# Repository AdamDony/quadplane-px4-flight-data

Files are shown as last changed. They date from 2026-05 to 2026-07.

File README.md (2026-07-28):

# Quadplane VTOL — Flight-Test Telemetry, CFD & Structural Data






Complete engineering dataset for a small **quadplane VTOL** (fixed wing + quad
lift motors): real flight-test telemetry through both hover ⇄ forward-flight
transitions, Ansys Fluent CFD of the S1223 wing, gust-response cases,
structural FEA, and the CAD geometry — with a Python toolkit that regenerates
every figure below straight from the raw logs.

> **Flight-Test Characterization and Design Implications of
> Hover-to-Forward-Flight Transition for a Small Quadplane VTOL Aircraft**
> Md Azizul Islam, Md Nur-A-Adam Dony\*, Mehedi Hasan, S. G. M. Hossain
> \* Corresponding author — `mdony42@tntech.edu`
> 📄 **[Read the paper (preprint PDF)](docs/preprint.pdf)**
> Journal manuscript, 2026 (under review)

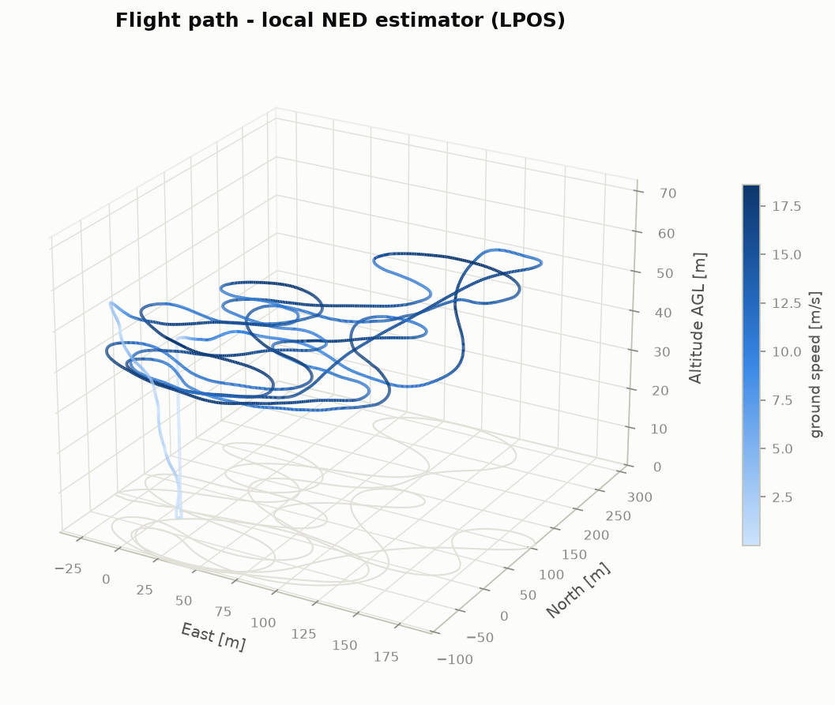
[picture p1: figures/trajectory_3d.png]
3-D flight path reconstructed from the PX4 local-position estimator


## The flight at a glance

Recorded **4 September 2022** over an open agricultural field near Dhaka,
Bangladesh (23.85° N, 90.51° E). One battery, one continuous log: vertical
take-off on four lift rotors, transition to wing-borne cruise, ~4 min of
pattern flying, back-transition, and vertical landing.

| | |
|---|---|
| Log session / flight time | 24.0 min / ~6 min |
| Distance flown | **3.6 km** |
| Max altitude (AGL) | **69 m** |
| Cruise indicated airspeed | **≈ 15 m/s** (18.6 m/s peak ground speed) |
| Power in stable hover | **≈ 1 270 W** |
| Power in wing-borne cruise | **≈ 380 W — 3.4× less than hover** |
| Energy used | 2 695 mAh (6S Li-Po) |

That 3.4× hover-to-cruise power ratio *is* the quadplane argument, and you can
see it in the data:

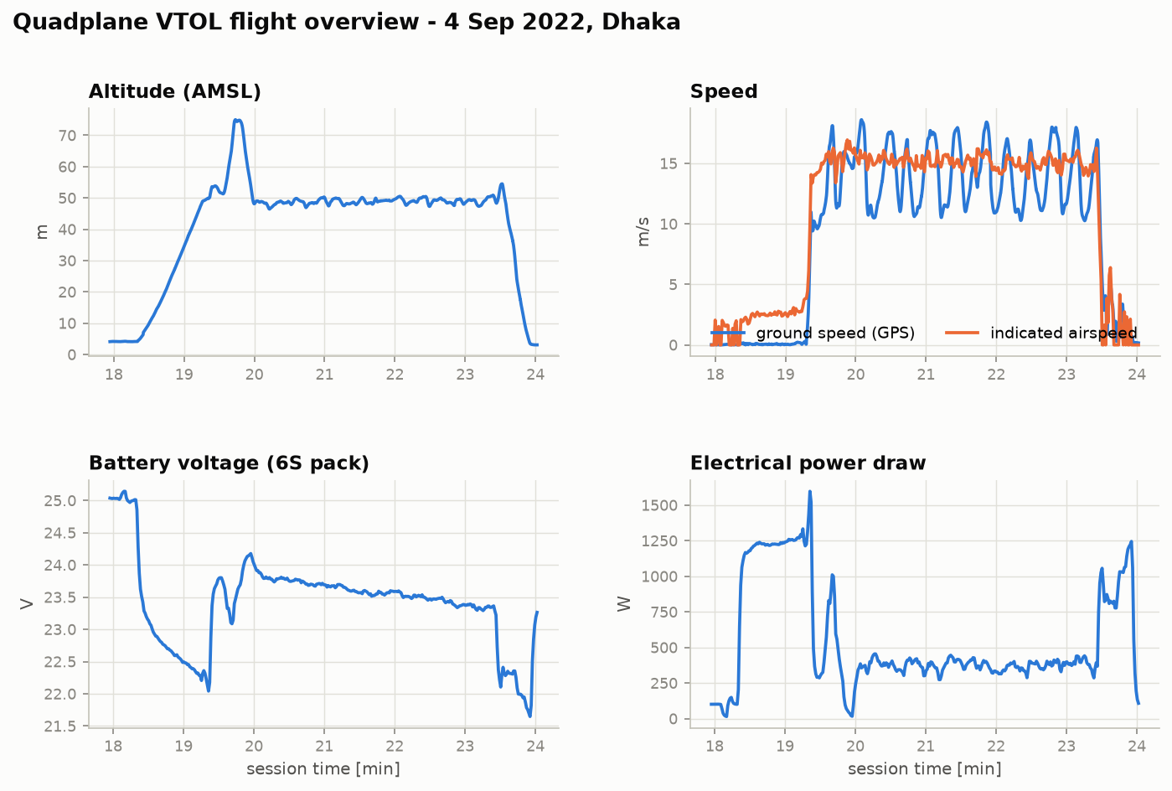
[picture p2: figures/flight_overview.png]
Altitude, speed, battery voltage and power over the flight


The transition itself — quad lift motors throttle up for the vertical climb,
shut off completely at 19.4 min as the wing takes the load, then re-engage at
23.4 min for the back-transition and landing:

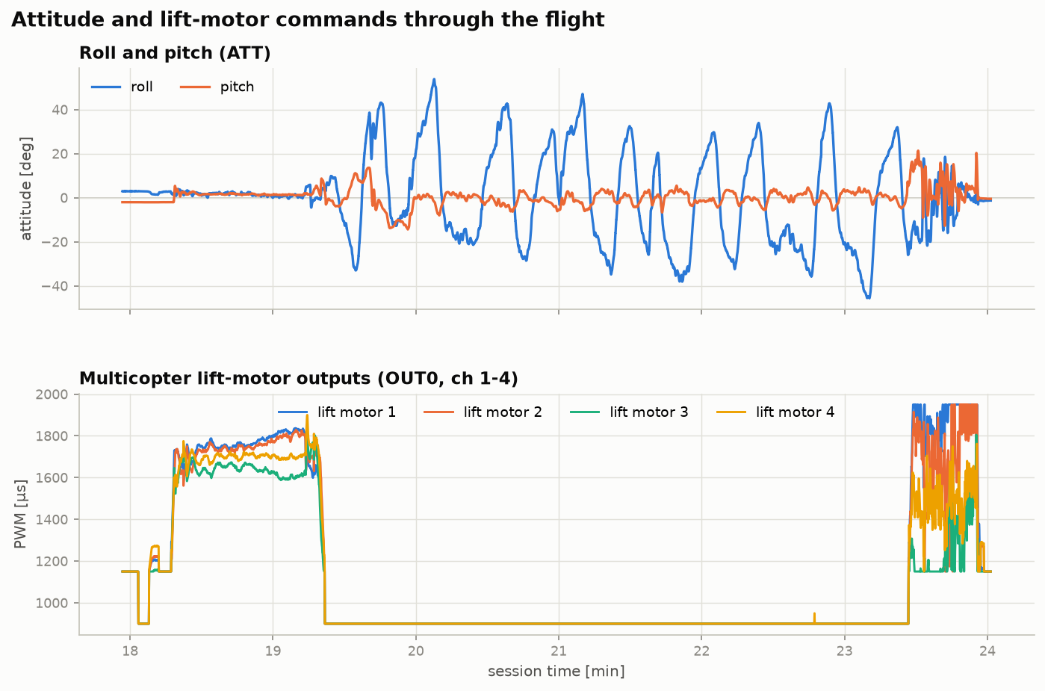
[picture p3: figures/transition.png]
Attitude and lift-motor PWM through both transitions


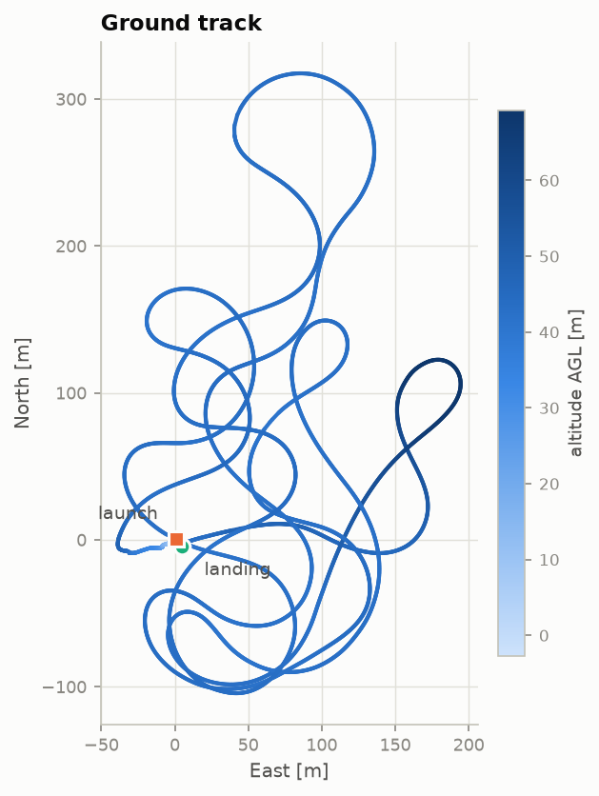
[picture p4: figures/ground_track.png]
Top-down ground track coloured by altitude


**Reproduce all figures** (≈10 s, no autopilot tooling required):

```bash
pip install -r analysis/requirements.txt
python analysis/plot_flight.py
```

---

## Repository map

```
├── data/telemetry/     13 PX4 topic CSVs from the flight log  → docs/DATA_DICTIONARY.md
├── analysis/           Python toolkit that generates figures/ from the CSVs
├── figures/            Flight-report figures (regenerable)
├── cfd/
│   ├── aoa-sweep/      Fluent pressure/lift/drag fields, α = −5° … +20°
│   ├── gust-cases/     Gust-perturbation lift & drag time-histories
│   ├── polars/         Aggregated Cl/Cd data (LiftDrag.xlsx) and plots
│   ├── flow-viz/       Streamlines, vectors, contours, residuals, case setup
│   └── projects/       Ansys Workbench projects (.wbpj + archives)
├── fea/                Wing structural FEA (deformation, stress, strain)
├── airfoil/            S1223 coordinates & meshing scripts (10″, 11.5″ chord, winglet)
├── cad/                SolidWorks parts, STEP export, AutoCAD drawing, renders
├── media/              Flight-test video
└── docs/               Data dictionary, paper source bundle (AIAA.zip)
```

---

## 1. Flight telemetry — `data/telemetry/`

Source binary log: `log_5_2022-9-4-18-02-56.px4log` (PX4 **v1.7.0**, legacy
`sdlog2` format), split into per-topic CSVs with `sdlog2_dump.py` from the
[PX4 v1.7.0 release tag](https://github.com/PX4/PX4-Autopilot/tree/v1.7.0).
Full column-level semantics: **[docs/DATA_DICTIONARY.md](docs/DATA_DICTIONARY.md)**.

| CSV | Topic | ~Rate | Highlights |
|---|---|---|---|
| `ATT.csv` | Attitude (quaternion, Euler, body rates) | 22 Hz | Transition body-rate peaks |
| `ATSP.csv` | Attitude setpoint | 22 Hz | Commanded pitch through transition |
| `ARSP.csv` | Attitude-**rate** setpoint (inner loop) | 86 Hz | Rate-controller commands |
| `AIRS.csv` | Airspeed (indicated / true) | 1 Hz | Transition speed, cruise IAS |
| `LPOS.csv` | Local NED position estimate | 22 Hz | 3-D trajectory, climb rates |
| `LPSP.csv` | Local position setpoint | event | Tracking error |
| `GPOS.csv` | Global position estimate | 22 Hz | Ground track, altitude |
| `GPS.csv` | Raw GNSS (+ the only absolute clock) | 1 Hz | Fix quality, 32 satellites |
| `OUT0.csv` | Actuator PWM, main bank | 10 Hz | Lift-motor shutoff / re-engagement |
| `RC.csv` | Pilot radio input | 9 Hz | Stick inputs |
| `BATT.csv` | Battery V / I / consumed mAh | 1 Hz | Per-phase power & energy |
| `PWR.csv` | 5 V rail health | 1 Hz | Power-system diagnostics |
| `STAT.csv` | System state (mode, arming, land detector) | event | Flight-phase segmentation |

> **Note.** `ARSP` in `sdlog2` is the attitude-*rate* setpoint topic, not
> airspeed — airspeed lives in `AIRS`. Newer PX4 releases use ULog (`.ulg`);
> the pipeline here is specific to the legacy `sdlog2` format.

## 2. CFD — Ansys Fluent, S1223 wing section

2-D angle-of-attack sweep with the SST k–ω turbulence model
(y⁺ ≲ 1 C-grid, V∞ = 15 m/s, ρ = 1.225 kg/m³, turbulence intensity 1 %).

- **`cfd/aoa-sweep/`** — pressure-field + integrated lift/drag exports at
  α = −5°, 0°, +5°, +10°, +15°, +20° (`AnsysSimu{α}AOA{Lift|Drag}.JPG`).
- **`cfd/gust-cases/`** — `15AoA{45|60}Gusted{2|4|6|8}MS{Lift|Drag}.jpg`:
  lift/drag time-histories at base α = +15° under 2–8 m/s gusts at 45°/60°
  orientation, plus static cases `{Lift|Drag}0AoA{30…135}Degree8ms.JPG`.
  The ~33 % gust lift-drop result in the paper comes from the 2 m/s case.
- **`cfd/polars/`** — [`LiftDrag.xlsx`](cfd/polars/LiftDrag.xlsx): the raw
  integrated Fluent forces behind the paper's polar figure, with plot exports.
  Run `python analysis/cfd_polars.py` to reduce them to finite-wing
  coefficients for the simulated panel geometry (`cad/WingForSimu.STEP`,
  0.292 m chord × 1.016 m span, AR 3.48): C_Lα ≈ 2.64/rad, C_D0 ≈ 0.018,
  Oswald e ≈ 0.77, max L/D ≈ 10.
- **`cfd/flow-viz/`** — streamlines, velocity vectors, pressure contours,
  particle traces, residual/convergence history, and solver-setup screenshots.
- **`cfd/projects/`** — Ansys Workbench projects: `GustedWingProjectANSYS.wbpj`
  (AoA sweep) and `GustedWind.wbpj` (gust cases) + supporting archive.
  Requires Workbench 2022 R2 / 2023 R1 with a Fluent licence.

## 3. Structural FEA — `fea/`

Static pressure loading of the wing at 100 / 200 / 300 Pa equivalent inflow
pressure: total deformation (`Deform*Pa.JPG`), von-Mises and normal
stress/strain at 200 Pa, and the full Workbench Mechanical project
(`FEAWing_files.zip`).

## 4. Airfoil — `airfoil/`

The wing uses the low-Reynolds, high-lift **Selig S1223** section:
baseline coordinates (`S1223.xlsx`), chord scalings to 10″ and 11.5″,
winglet planform points, and the XFOIL/Fluent meshing scripts (`*.docx`).

## 5. CAD — `cad/`

SolidWorks wing and arm solids (`*.SLDPRT`), neutral `WingForSimu.STEP`
export for re-meshing in any tool, AutoCAD assembly drawing
(`Drawing1.dwg` / `Drawing1-Model.pdf`), and renders in `cad/renders/`.

## 6. Media — `media/`

Flight-test video from the 5 September 2022 session
([`VID-20220905-WA0012.mp4`](media/VID-20220905-WA0012.mp4)).

---

## Citing this work

If you use any data, figures, or analysis from this repository, please cite
the paper (machine-readable metadata in [`CITATION.cff`](CITATION.cff)):

```bibtex
@article{IslamDonyHossain2026Quadplane,
  author  = {Islam, Md Azizul and Dony, Md Nur-A-Adam and Hasan, Mehedi and Hossain, S. G. M.},
  title   = {{Flight-Test Characterization and Design Implications of
             Hover-to-Forward-Flight Transition for a Small Quadplane VTOL Aircraft}},
  year    = {2026},
  note    = {Journal manuscript under review}
}
```

Volume, pages, and DOI will be added on acceptance.

## License

Data, figures, and analysis code are released under
**[CC BY 4.0](LICENSE)**. Ansys project files are © the authors (CC-BY-4.0;
opening them requires your own Ansys licence — no Ansys software is
redistributed). The paper source bundle (`docs/AIAA.zip`) follows the
journal's author-rights policy.

## Contact

**Md Nur-A-Adam Dony** — `mdony42@tntech.edu`
Department of Electrical and Computer Engineering,
Tennessee Technological University, Cookeville, TN, USA

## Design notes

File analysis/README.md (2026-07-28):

# Analysis toolkit

Reproduces every figure in [`figures/`](../figures/) directly from the raw
telemetry CSVs in [`data/telemetry/`](../data/telemetry/).

```bash
pip install -r analysis/requirements.txt
python analysis/plot_flight.py            # flight figures (run from the repo root)
python analysis/cfd_polars.py             # CFD polar reduction -> figures/cfd_polars.png
```

Output (≈10 s):

| Figure | Contents |
|---|---|
| `figures/flight_overview.png` | Altitude, ground speed + indicated airspeed, battery voltage, electrical power |
| `figures/trajectory_3d.png` | 3-D flight path (local NED), coloured by ground speed |
| `figures/ground_track.png` | Top-down ground track, coloured by altitude AGL |
| `figures/transition.png` | Roll/pitch and quad lift-motor PWM through both VTOL transitions |
| `figures/cfd_polars.png` | Finite-wing C_L/C_D polars and induced-drag fit reduced from `cfd/polars/LiftDrag.xlsx` |

## Time-base caveat

The `sdlog2` CSV exports carry no per-row timestamp; only `GPS.csv` has an
absolute clock (`GPS_GPSTime`, µs). The script assigns each topic a uniform
time axis spanning the GPS-derived 24.02-min session. This is good to within
logger scheduling jitter and is intended for visualisation and phase-level
interpretation — not for spectral analysis. See
[`docs/DATA_DICTIONARY.md`](../docs/DATA_DICTIONARY.md) for column semantics.

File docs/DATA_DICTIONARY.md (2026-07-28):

# Telemetry data dictionary

Column-level reference for the 13 PX4 topic exports in [`data/telemetry/`](../data/telemetry/).

**Source log:** `log_5_2022-9-4-18-02-56.px4log` — PX4 v1.7.0, legacy `sdlog2`
binary format, extracted per-topic with `sdlog2_dump.py` from the
[PX4-Autopilot v1.7.0](https://github.com/PX4/PX4-Autopilot/tree/v1.7.0) release tag.

**Session:** 24.02 min total (bounded by the `GPS_GPSTime` microsecond clock),
of which the final ~6 min is the actual flight (arm → VTOL take-off →
transition → fixed-wing cruise → back-transition → landing).

**Time base:** the CSV rows do not carry a per-row timestamp column. Each topic
is logged at an approximately fixed rate while the logger runs, so a uniform
time axis over the 24.02-min session (as done in
[`analysis/plot_flight.py`](../analysis/plot_flight.py)) is accurate to within
scheduler jitter — sufficient for visualisation and phase-level analysis, not
for spectral/rate-sensitive work. The "rate" column below is simply
`rows / session length`.

Angles are radians, positions metres, velocities m/s, following PX4 `sdlog2`
conventions (NED frame: X north, Y east, Z **down**).

---

## ATT — vehicle attitude (~22 Hz, 31 885 rows)

| Column | Meaning |
|---|---|
| `ATT_qw, ATT_qx, ATT_qy, ATT_qz` | Attitude quaternion (body → NED) |
| `ATT_Roll, ATT_Pitch, ATT_Yaw` | Euler angles [rad] |
| `ATT_RollRate, ATT_PitchRate, ATT_YawRate` | Body angular rates [rad/s] |
| `ATT_GX, ATT_GY, ATT_GZ` | Estimated ground-relative velocity components (unused in this log) |

## ATSP — attitude setpoint (~22 Hz, 31 746 rows)

| Column | Meaning |
|---|---|
| `ATSP_RollSP, ATSP_PitchSP, ATSP_YawSP` | Commanded Euler angles [rad] |
| `ATSP_ThrustSP` | Normalised thrust setpoint [0–1] |
| `ATSP_qw…ATSP_qz` | Setpoint quaternion |
| `ATSP_fwy, ATSP_dmcy, ATSP_af, ATSP_tm, ATSP_eon, ATSP_di` | Controller flags (fw yaw-wheel, disable mc yaw, apply flaps, thrust-major, enabled, direct-input) |

## ARSP — attitude *rate* setpoint (~86 Hz, 123 738 rows)

| Column | Meaning |
|---|---|
| `ARSP_RollRateSP, ARSP_PitchRateSP, ARSP_YawRateSP` | Commanded body rates [rad/s] — inner-loop setpoints |

> Note: despite the name, `ARSP` in `sdlog2` is the attitude-**rate** setpoint
> topic, not airspeed. Airspeed is in `AIRS`.

## AIRS — airspeed (~1 Hz, 1 445 rows)

| Column | Meaning |
|---|---|
| `AIRS_IndSpeed` | Indicated airspeed [m/s] |
| `AIRS_TrueSpeed` | True airspeed [m/s] |
| `AIRS_AirTemp` | Air temperature [°C] |
| `AIRS_Conf` | Sensor confidence [0–1] |

## LPOS — local position estimate (~22 Hz, 31 157 rows)

| Column | Meaning |
|---|---|
| `LPOS_X, LPOS_Y, LPOS_Z` | Local NED position [m] (Z positive **down**) |
| `LPOS_Dist, LPOS_DistR` | Distance-sensor reading and rate |
| `LPOS_VX, LPOS_VY, LPOS_VZ` | NED velocity [m/s] |
| `LPOS_RLat, LPOS_RLon, LPOS_RAlt` | Local-frame reference origin (lat/lon/alt) |
| `LPOS_PFlg, LPOS_GFlg` | Position / ground-distance validity flags |
| `LPOS_EPH, LPOS_EPV` | Horizontal / vertical position std-dev [m] |

## LPSP — local position setpoint (event, 6 599 rows)

| Column | Meaning |
|---|---|
| `LPSP_X, LPSP_Y, LPSP_Z, LPSP_Yaw` | Position + yaw setpoint |
| `LPSP_VX, LPSP_VY, LPSP_VZ` | Velocity setpoint [m/s] |
| `LPSP_AX, LPSP_AY, LPSP_AZ` | Acceleration setpoint [m/s²] |

## GPOS — global position estimate (~22 Hz, 31 010 rows)

| Column | Meaning |
|---|---|
| `GPOS_Lat, GPOS_Lon` | WGS-84 latitude / longitude [deg] |
| `GPOS_Alt` | Altitude AMSL [m] |
| `GPOS_VelN, GPOS_VelE, GPOS_VelD` | NED velocity [m/s] |
| `GPOS_EPH, GPOS_EPV` | Position accuracy estimates [m] |
| `GPOS_TALT` | Terrain altitude [m] (−1 = invalid) |

## GPS — raw GNSS (~1 Hz, 1 484 rows)

| Column | Meaning |
|---|---|
| `GPS_GPSTime` | GPS epoch time [µs] — **the only absolute clock in the dataset** |
| `GPS_Fix` | Fix type (4 = 3D-RTK class fix in this log) |
| `GPS_EPH, GPS_EPV` | Horizontal / vertical accuracy [m] |
| `GPS_Lat, GPS_Lon, GPS_Alt` | Raw receiver position |
| `GPS_VN, GPS_VE, GPS_VD` | Receiver NED velocity [m/s] |
| `GPS_Cog` | Course over ground [rad] |
| `GPS_nSat` | Satellites used |
| `GPS_SNR, GPS_N, GPS_J, GPS_H` | Signal metrics (noise, jamming indicator/level) |

## OUT0 — actuator outputs, main bank (~10 Hz, 13 792 rows)

| Column | Meaning |
|---|---|
| `OUT0_Out0 … OUT0_Out3` | Quad lift-motor PWM [µs] (900 = off, ≈1150 = armed idle) |
| `OUT0_Out4 … OUT0_Out7` | Remaining main-bank channels (fixed-wing surfaces / pusher) |

## RC — pilot radio input (~9 Hz, 13 534 rows)

| Column | Meaning |
|---|---|
| `RC_C0 … RC_C11` | Normalised channel values [−1 … 1] |
| `RC_RSSI` | Link signal strength |
| `RC_CNT, RC_Lost, RC_Drop` | Frame counter, link-lost flag, drop count |

## BATT — battery status (~1 Hz, 1 442 rows)

| Column | Meaning |
|---|---|
| `BATT_VFilt` | Filtered pack voltage [V] (6S Li-Po) |
| `BATT_CFilt` | Filtered current [A] |
| `BATT_Discharged` | Consumed charge [mAh] |
| `BATT_Remaining, BATT_RemainingV` | Remaining-capacity estimates [0–1] |
| `BATT_Warning` | Low-battery warning level |

## PWR — power-rail status (~1 Hz, 1 439 rows)

| Column | Meaning |
|---|---|
| `PWR_Periph5V, PWR_Servo5V` | 5 V peripheral / servo rail voltages [V] |
| `PWR_RSSI` | RSSI analog input |
| `PWR_UsbOk, PWR_BrickOk, PWR_ServoOk` | Power-source validity flags |
| `PWR_PeriphOC, PWR_HipwrOC` | Over-current flags |

## STAT — system status (event, 7 237 rows)

| Column | Meaning |
|---|---|
| `STAT_NavState` | Navigation/flight-mode state (0 = manual, 3 = mission/auto in this log) |
| `STAT_ArmS` | Arming state |
| `STAT_Failsafe` | Failsafe active flag |
| `STAT_Landed` | Land-detector output |
| `STAT_Load` | CPU load [0–1] |

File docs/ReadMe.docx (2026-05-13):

- WingForSimu.SLDPRT is the SolidWorks part file used for doing CFD ANSYS Fluent Analysis
- Drawing1.dwg is the AutoCAD file for 2D wing drawing
- WingDraft2.SLDPRT is the SolidWorks part file for wing 3D Modeling
- Any files that start with S1223 is the files contain the xy coordinates of S1223 airfoil that is used in SolidWorks 3D modeling
- The rest of the files are screenshots of various things

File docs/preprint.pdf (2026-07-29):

# Flight-Test Characterization and Design Implications of Quadplane Hover-to-Forward-Flight Transition

Md Azizul Islam∗

# KaiLab LLC, Sugar Land, TX 77479, United States

Md Nur-A-Adam Dony†

# Tennessee Technological University, Cookeville, TN 38505, United States

Mehedi Hasan‡

# University of Arkansas, Fayetteville, AR 72701, United States

S. G. M. Hossain§

# Blue Origin, Kent, WA 98032, United States

Hybrid vertical take-off and landing aircraft that combine multirotor lift with a fixed wing

pair the operational flexibility of a multicopter with the cruise efficiency of an airplane, at the

cost of a mode-switching transition that must remain reliably stable. This paper reports a

flight-test characterization of the hover phase, the hover-to-forward-flight transition, and the

fixed-wing cruise of a small quadplane, using telemetry recorded by an open-source autopilot,

complemented by a computational aerodynamic study of the wing. Body angular rates, attitude

excursions, ground speed, electrical power, bank-angle distributions, and elevator trim are

extracted from the on-board estimator and cross-validated against numerical derivatives of

the recorded attitude quaternion. The aircraft exhibits a stationary hover, a smooth front

transition completing at an airspeed of 11.9 meters per second, and a back transition completing

in 1.86 seconds, with peak body-axis rates well within control authority. The hover-to-cruise

electrical-power ratio is 3.36. An angle-of-attack sweep of a finite wing panel resolves the lift

and drag polars, identifies the onset of stall, and quantifies an approximately 33 percent lift

loss under a quasi-steady airspeed deficit, anchoring an operational wind ceiling. Design rules

for airspeed margin, control authority, power sizing, energy budget, and wind tolerance are

derived.

# Nomenclature

∗Research and Development Specialist, UAV Design and Manufacture; azizul@kailab.com.

†Ph.D. Candidate, Department of Electrical and Computer Engineering; mdony42@tntech.edu (Corresponding Author).

‡Graduate Research Assistant, Department of Mechanical Engineering; mehedih@uark.edu.

§Senior Manufacturing Engineer, Lunar Permanence Program; smgmamur@yahoo.com.

φ, θ, ψ | = | roll, pitch, yaw angles, rad (deg where stated)
p, q, r | = | body-axis angular rates, rad/s (deg/s where stated)
qw, qx, qy, qz | = | unit attitude quaternion components
VN , VE, VD | = | north–east–down (NED) frame ground velocity, m/s
Vℎ | = | horizontal ground speed, m/s
Vair | = | indicated airspeed (IAS) from pitot, m/s
VT, VT,back | = | front and back transition airspeeds, m/s
Vc | = | cruise airspeed, m/s
ℎ, ℎ¤ | = | altitude above ground level and climb rate, m, m/s
δe, δa, δr | = | elevator, aileron, rudder deflection, deg
R | = | turn radius, m
P, E | = | electrical power and energy, W, W·h
Vbat, I | = | battery pack voltage and current, V, A
L, D, T | = | aerodynamic lift, drag, and thrust, N
CL, CD, CM | = | lift, drag, and pitching-moment coefficients
CLα | = | lift-curve slope, rad−1
α | = | angle of attack, rad (deg where stated)
n | = | load factor
W | = | aircraft weight, N
g | = | gravitational acceleration, m/s2
ρ, μ | = | air density and dynamic viscosity, kg/m3
, Pa·s
S, c, b | = | wing reference area, chord, and span, m2
, m, m
Re | = | chord Reynolds number
ηprop, ηESC | = | propeller and electronic-speed-controller efficiency
Nr | = | number of lift rotors
Ad | = | single-rotor disc area, m2
σ | = | sample standard deviation

# I. Introduction

# A. Background and Motivation

H

ybrid VTOL UAVs combine the runway-independent operation of a multicopter with the cruise efficiency of a

fixed-wing aircraft, and have become a preferred platform for medium-range surveillance, mapping, and logistics missions [1, 2]. The development of small UAV airframes has progressed from early FPGA-based remote-piloted

platforms [3] and digital multi-rotor control systems [4] toward autonomous open-source autopilot ecosystems, and

wing design choices for small UAVs now span fixed cambered low-Reynolds-number sections to more sophisticated

morphing-airfoil concepts [5–7]. Among hybrid configurations, the quadplane—a conventional airplane retrofitted with

four dedicated lift rotors—offers the simplest control architecture: the multicopter (MC) and fixed-wing (FW) flight

modes are mechanically decoupled, and the autopilot manages a single coordinated handover during transition. The

trade-off is that the lift rotors carry parasitic mass and drag in cruise, while the wing and pusher are unused in hover, so

the platform must be efficient enough in cruise to amortize the parasitic systems [8]. The test vehicle used in this study

is shown at rest in Fig. 1, with the composite-skinned airframe, twin lift booms, and rear pusher motor visible.

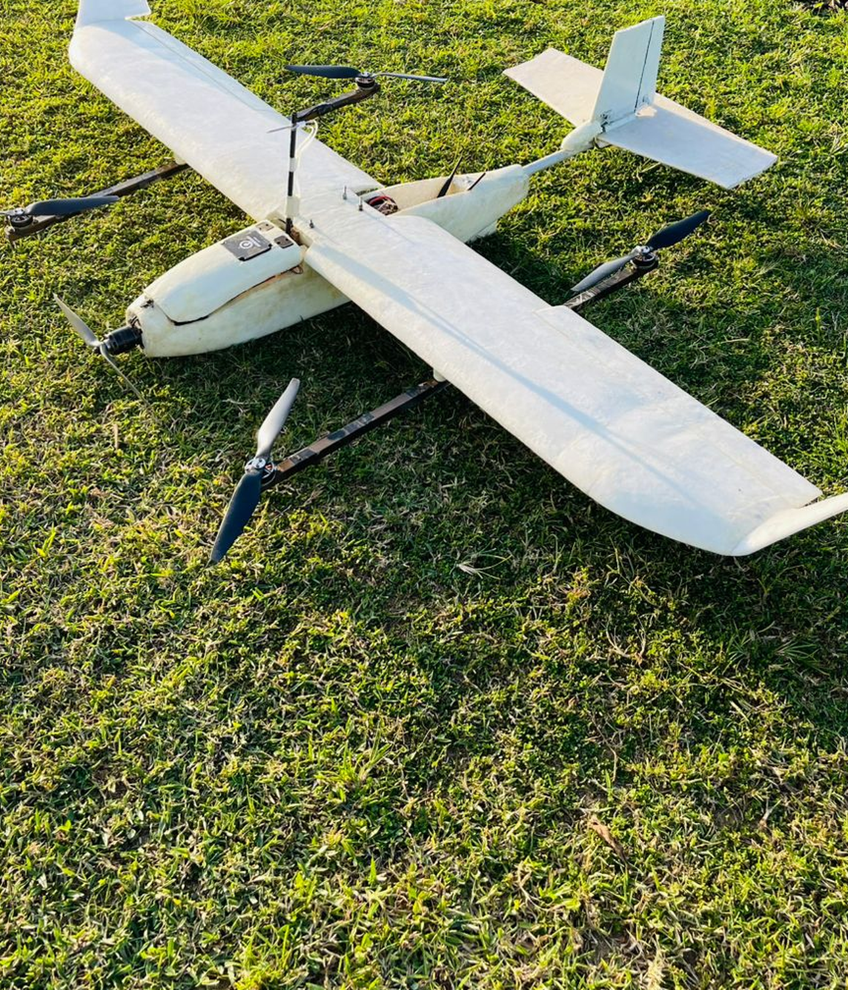
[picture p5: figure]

Fig. 1 Test vehicle at rest: a small quadplane with four boom-mounted lift rotors and a rear pusher propeller.

The most demanding flight regime is the front transition (MC→FW), during which the wing must develop sufficient

lift to support the aircraft before the lift rotors are commanded off. If transition is initiated too slowly, the wing stalls; if

too quickly, the lift rotors saturate while fighting decelerating wing downwash [9, 10]. Practical PX4-class autopilots

manage this trade through a single threshold airspeed VT at which the controller commits to FW.∗ Robust transition is

therefore a stability problem first—the airframe must remain trim during a regime change in which control authority

transfers from rotors to aerodynamic surfaces—and a design problem second—the airframe must possess sufficient

power, control, and aerodynamic margins to accommodate the worst-case excursion.

∗PX4 User Guide: VTOL Aircraft Configuration, https://docs.px4.io/main/en/frames_vtol/ [retrieved 12 May 2026].

# B. Related Work

The literature on small VTOL UAV transition control spans three configurations. Tail-sitter aircraft have dominated

empirical work: Beach et al. [11] introduced a resolved tilt-twist attitude representation that avoids the Euler-angle

singularities of a 90° pitch swing, Lyu et al. [12] demonstrated hierarchical attitude control on a quadrotor tail-sitter,

Verling et al. [13] reported full-attitude transition on a flying-wing tail-sitter, Kubo and Suzuki [14] characterized

tail-sitter transitional flight, and Ritz and D’Andrea [15] introduced a global flight-envelope controller for flying-wing

tail-sitters. Tilt-rotor and tilt-wing aircraft have been studied by Maqsood and Go [9] on transition optimization,

Geuther et al. [16] on a NASA tandem tilt-wing demonstrator, Yeh et al. [17] on an inverse machine-learning approach

to tilt-wing takeoff, and May et al. [18] on tilt-wing transition strategies. Quadplanes have received comparatively

less empirical attention: Mathur and Atkins [19] reported an experimental aerodynamic analysis of a quadplane UAS

in the wind tunnel, Lee and Kim [20] proposed MPC-based longitudinal control for a fixed-wing VTOL, Liu et al.

[10] demonstrated INDI transition control on a small VTOL, and Chiwande et al. [21] presented adaptive transition

control for quadplane VTOLs in urban gust environments. Survey work [1, 2, 8] consistently identifies the lift+cruise

quadplane as the simplest and most energy-efficient hybrid topology for medium-range missions. The control-theoretic

background for VTOL and related aerospace platforms is a parallel theme: parametric-uncertainty tracking control for

VTOL vehicles has been developed in [22], distributed formation control of spacecraft and higher-order-dynamics UAVs

in [23, 24], command-filtered robust tracking on marine and surface platforms in [25], and safe reinforcement-learning

control with control barrier functions in [26, 27], providing complementary algorithmic context for the experimental

characterization reported here.

# C. Comparison with Existing Methods and Contributions

Three characteristics of prior empirical literature motivate the present work. First, many published flight-test

characterizations rely on proprietary autopilot stacks whose raw telemetry is not openly accessible. Second, the bulk of

VTOL transition work is simulation-led, with flight data appearing as a single validation point rather than the primary

characterization tool. Third, the configuration-specific literature is heavily weighted toward tail-sitter and tilt-rotor

designs, while empirical studies that report stability margins, transition timing, power budgets, and aerodynamic

interpretation jointly on a quadplane platform are sparse.

Table 2 summarizes the scope of representative prior studies and contrasts each with the present work along

eight axes: aircraft configuration, methodology, primary data source, transition-airspeed reporting, transition-duration

reporting, power-budget reporting, lateral-directional characterization, and CFD aerodynamic interpretation. No prior

study in the table simultaneously satisfies the joint empirical+CFD+design-rule scope on a quadplane platform.

This paper contributes the following, none of which is jointly addressed in the prior literature reviewed:

1) Configuration focus on quadplanes. Where prior empirical transition work largely targets tail-sitters [11–15]

Table 2 Comparison of the present work with representative prior literature on small VTOL UAV transition. ✓ = reported in primary text; ✗ = not reported. Configuration codes: TS = tail-sitter; FW = flying-wing; Quad. = quadrotor. Data codes: “Emp.” = empirical (real-flight); “Sim.” = simulation; “WT” = wind tunnel.

Reference | Config. | Methodology | Data | VT | Dur. | Pow. | Lat./dir. | CFD
Beach 2014 [11] | TS | Tilt-twist attitude | Sim.+flight | ✗ | ✗ | ✗ | ✗ | ✗
Lyu 2017 [12] | Quad. TS | Hierarchical attitude | Emp. | ✓ | ✓ | ✗ | partial | ✗
Verling 2016 [13] | FW TS | Full-attitude | Emp. | ✓ | ✓ | ✗ | ✓ | ✗
Kubo 2008 [14] | TS | Transitional flight | Emp.+WT | ✓ | ✓ | ✗ | ✗ | WT
Ritz 2017 [15] | FW TS | Global envelope | Emp. | ✓ | ✓ | ✗ | ✓ | ✗
Maqsood 2012 [9] | Tilt-rotor | Aerodynamic vectoring | Sim. | ✓ | ✓ | ✗ | ✗ | Invisc.
Geuther 2020 [16] | Tilt-wing | Sub-scale free-flight | Emp. | ✓ | partial | ✗ | partial | ✗
Yeh 2023 [17] | Tilt-wing | Inverse-ML takeoff | Sim. | ✓ | ✗ | ✗ | ✗ | ✗
May 2024 [18] | Tilt-wing | Transition strategy | Sim. | ✓ | ✓ | ✗ | partial | ✗
Mathur 2023 [19] | QuadPlane | Wind-tunnel aerodynamics | WT | ✗ | ✗ | ✗ | ✗ | ✓ (WT)
Lee 2024 [20] | FW VTOL | MPC longitudinal | Sim. | ✓ | ✗ | ✗ | ✗ | ✗
Chiwande 2025 [21] | QuadPlane | INAV adaptive gust | Emp. | partial | ✗ | ✗ | partial | ✗
This work | Quadplane | PX4 sdlog2 + Fluent CFD | Emp.+CFD | ✓ | ✓ | ✓ | ✓ | ✓ (CFD)

or tilt-wing and tilt-rotor airframes [9, 16–18], this paper provides a flight-test characterization of a small

quadplane—a configuration that remains under-represented in the empirical literature [1, 19].

2) Open, reproducible methodology. The telemetry pipeline operates exclusively on the open-source PX4 sdlog2

record. Every derived state—quaternion-to-Euler, body rates, ground speed, wind, power, energy, bank, turn

radius, elevator trim—is cross-validated against firmware-stored fields, and per-topic CSV bundles are released

(see Data Availability). The wind-tunnel work of Mathur and Atkins [19] provides aerodynamic data on a

comparable platform; the present approach complements it with real-flight evidence.

3) Joint longitudinal and lateral-directional characterization on a single flight. Body-rate, attitude, transition-

timing, bank-angle distribution, coordinated-turn cross-check, and elevator-trim results are derived from the

same flight log. No reviewed quadplane study reports all six on real flight data.

4) CFD aerodynamic interpretation with gust anchoring. An Ansys Fluent angle-of-attack sweep of a finite-span

S1223 wing panel gives CL (α) and CD (α) polars with a quantitative drag-polar decomposition (zero-lift drag

and Oswald factor), multi-AoA pressure contours, flow visualization, and a quasi-steady airspeed-deficit case

that converts the empirical VT threshold into a physically anchored, gust-margin-quantified design quantity.

5) Inequality-form design rules. Airspeed margin, control authority, power-system sizing, energy budget, and

operational wind ceiling are translated from the combined empirical and CFD evidence into compact design

inequalities (Sec. VIII).

The results derive from a single flight on one airframe and constitute a case study; broader statistical validation

through additional flights and platforms is identified as the central future-work theme (Sec. IX).

The remainder of the paper is organized as follows. Section II presents the mathematical preliminaries. Section III describes the data-extraction and CFD methodologies, together with the aerodynamic and energetic relations specific to

the quadplane configuration. Sections IV and V describe the test vehicle and the experimental setup. Section VI reports

the flight-test results. Section VII presents the computational aerodynamic analysis. Section VIII extracts the design

implications, and Section IX concludes.

# II. Preliminaries

This section establishes the mathematical framework used to derive aircraft states from the recorded PX4 telemetry

and from the complementary CFD sweep. All symbols are defined in the Nomenclature.

# A. Attitude Representation

The aircraft attitude is stored on board as a unit quaternion q = (qw, qx, qy, qz ) with q

2
w + q

2
x + q

2
y + q

2
z = 1. The

corresponding Tait–Bryan Euler angles (yaw–pitch–roll, Z-Y-X intrinsic rotation) follow [28–30]

# φ = atan2

## 2(qwqx + qy qz ), 1 − 2(q

2
x + q

2

y

)

, | (1)

θ = arcsin-

## 2(qwqy − qzqx)

, | (2)

# ψ = atan2

## 2(qwqz + qx qy), 1 − 2(q

2
y + q

2

z

)

| (3)

# B. Body Angular-Rate Kinematics

The relationship between body-axis angular rates (p, q, r) and Euler-angle rates is [28, 30]

p

q

r

=

1 | 0 | − sin θ
0 | cos φ | sin φ cos θ
0 | − sin φ | cos φ cos θ

φ¤

θ¤

ψ¤

, | (4)

which is valid in the non-singular range |θ| < π/2.

# C. Ground Speed, Airspeed, and Wind

The horizontal ground speed is Vℎ =

√︃
V

2
N

+ V

2
E

and the climb rate is ℎ¤ = −VD. In a stationary hover (Vℎ ≈ 0), the

steady wind component along the aircraft body-x axis is

Vwind ≈ Vair − Vℎ | (5)

# D. Electrical Power, Energy, and Endurance

Instantaneous electrical power, accumulated energy, and pure-phase endurance are

## P(t) = Vbat(t) I(t), E =

∫ t1

t0

### P(t) dt, tphase =

## Epack

P¯
phase
, | (6)

and the mission-average power for a hover-duty fraction ηℎ is

## P¯mission = ηℎ P¯

## hover + (1 − ηℎ) P¯

cruise | (7)

# E. Coordinated Turn and Load Factor

In a coordinated turn at airspeed V and bank angle φ, the horizontal force balance yields [29, 31]

R =

V

2

## g tan φ

, ψ¤ =

## g tan φ

V

, n =

1

cos φ

, | (8)

with n the load factor. The turn radius R can be cross-checked kinematically from the observed yaw rate as R = Vℎ/|ψ¤|;

agreement of the two estimates indicates negligible side-slip.

# F. Elevator Trim

For a standard servo with neutral pulse-width-modulation (PWM) command 1500 µs and full deflection ±δmax at

±500 µs, the commanded elevator angle is

## δe [deg] =

## PWM − 1500

500 | δmax | (9)

# G. Aerodynamic Forces and Reynolds Number

Lift, drag, and pitching moment on a wing of reference area S and chord c at airspeed V are

L =

## 1/2 ρV²

## S CL (α), D =

## 1/2 ρV²

## S CD (α), M =

## 1/2 ρV²

Sc CM (α) | (10)
In the linear regime, CL (α) ≈ CL0 + CLα α with CLα | = dCL/dα the lift-curve slope. | The drag polar follows the

parabolic approximation

## CD (α) ≈ CD0 + k C²

L

(α), | (11)

## with CD0

the zero-lift drag coefficient and k the induced-drag factor. The chord Reynolds number is

Re =

## ρVc

μ

, | (12)

and the lift-to-drag ratio is

L

D

=

## CL (α)

## CD (α)

, | (13)

maximized when dCD/dCL = CD/CL. Low-Reynolds-number effects on CL,max and drag are reviewed in [32–34].

# III. Methodology

This section describes the methodology in four parts: the binary-log data-extraction pipeline (Sec. III.A); the

numerical operators that produce the results of Sec. VI (Sec. III.B); the aerodynamic and energetic balance equations

that connect the flight measurements to the airframe’s design quantities (Sec. III.C); and the Ansys Fluent setup used for

the complementary aerodynamic sweep of Sec. VII (Sec. III.D). The end-to-end methodology is summarized in Fig. 2.

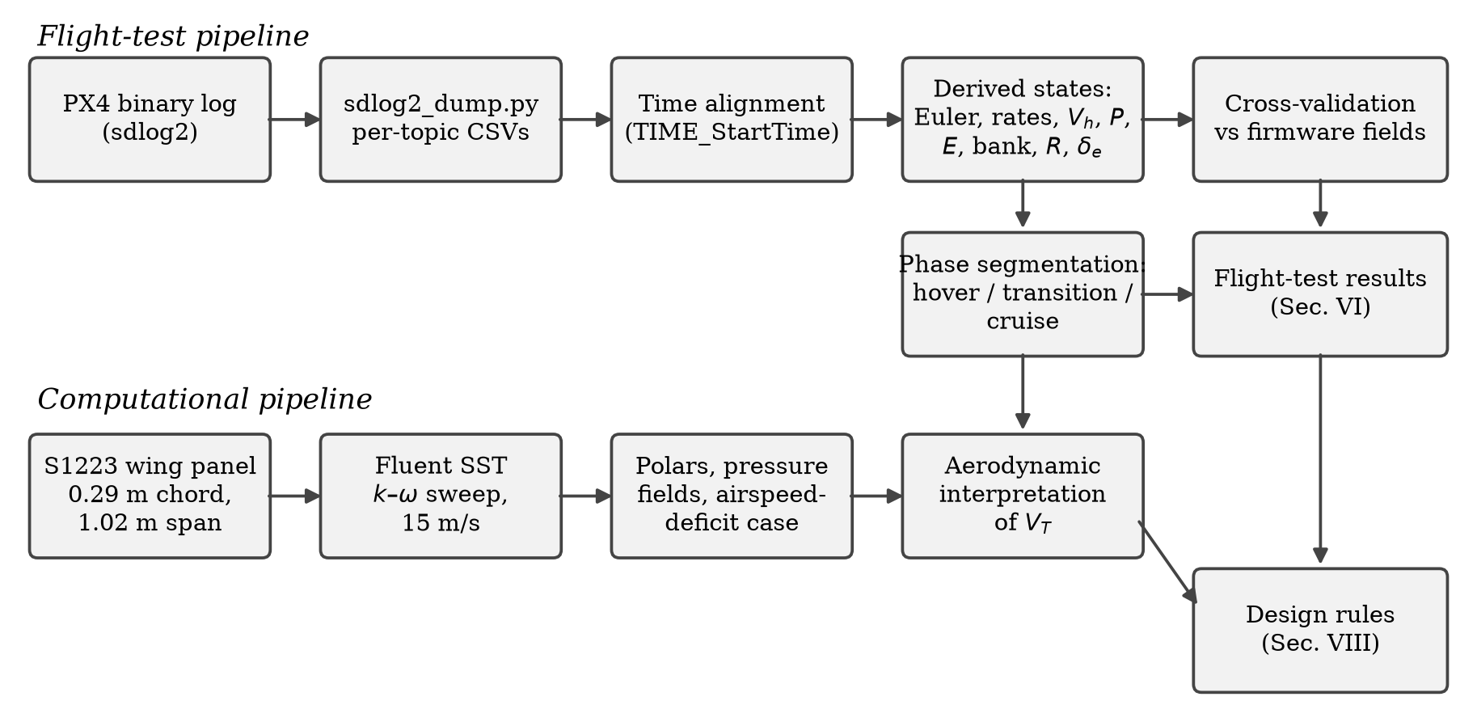
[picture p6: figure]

Fig. 2 End-to-end methodology: the flight-test pipeline from binary log to phase-resolved results, and the computational pipeline from wing-panel geometry to the aerodynamic interpretation, converging on the design rules.

# A. Data Extraction from the sdlog2 Binary Format

The PX4 binary log used in this study is in the legacy sdlog2 format, identified by the file-leading magic

bytes 0xA3 0x95 0x80. | Each message is preceded by a three-byte header (0xA3 0x95 <MSG_TYPE>); the FMT mes-
sage (<MSG_TYPE>=0x80) declares the binary layout of all subsequent message types. | The file is parsed using

sdlog2_dump.py from the PX4-Autopilot v1.7.0 release tag, which produces per-topic CSV outputs filtered with

the -m option. Global time alignment is performed by forward-filling the TIME_StartTime field, giving every row a

microsecond-precision wall-time coordinate.

The following topics are used: ATT (attitude quaternion and body rates, ∼250 Hz); ATSP (attitude setpoint); AIRS

(calibrated indicated airspeed, ∼1 kHz); BATT (filtered pack voltage and current); LPOS and LPSP (local position

estimator and setpoint); GPOS (global position); OUT0 and OUT1 (PWM commands); and VTOL (mode flags). Euler

angles obtained from Eqs. (1)–(3) are verified against the firmware-stored ATT_Pitch, ATT_Roll, and ATT_Yaw fields

to residuals below 2 × 10−6

°, and body rates from ATT_*Rate are cross-validated against numerical Euler-angle

derivatives obtained via Eq. (4).

# B. Numerical Operators on Per-Topic Samples

The CSV samples are non-uniform. Numerical derivatives are computed by centred differences,

x¤i ≈

xi+1 − xi−1

### ti+1 − ti−1

(14)

Phase-window integrals [Eq. (6)] are evaluated by the trapezoidal rule,

E ≈

N

∑︁−1

i=0

1/2

## P(ti) + P(ti+1)

(ti+1 − ti) | (15)

Per-phase statistics use the unbiased sample estimators

x¯ =

1

N

∑︁

N

i=1

xi

, | σ2 x =

1

N − 1

∑︁

N

i=1

xi − x¯

2
. | (16)

A state is reported as “essentially zero in the mean” when |x¯| < σx.

Phase windows are identified using the recorded rotor-wing and transition flags. Let fRw(t) and fTr(t) denote the

rotor-wing and transition indicators. The phase logic is

phase(t) =

MC hover | fRw = 1, fTr = 0, Vℎ < 0.5 m/s,
MC→FW transition | fTr = 1,

¤fRw < 0,

FW cruise | fRw = 0, fTr = 0,
FW→MC transition | fTr = 1,

¤fRw > 0,

(17)

with the MC→FW and FW→MC branches distinguished by the sign of the rotor-wing edge. The cruise window for

elevator-trim analysis is further restricted to samples satisfying the level-flight criterion |φ| < 5

◦

and |ℎ¤| < 0.5 m/s.

# C. Aerodynamic and Energetic Balance Specific to the Quadplane

For a quadplane operating at the autopilot-held cruise airspeed Vc, four balance equations connect the empirical

measurements of Sec. VI to the airframe’s design quantities. In level steady cruise, the lift balances the weight,

## 1/2 ρV²

c S Ccruise

# L = W =⇒ C

cruise
L | =

2W

## ρV²

c S

, | (18)

and the pusher thrust balances the drag,

## Tpusher = D =

## 1/2 ρV²

c S Ccruise
D | (19)

The corresponding electrical power required at the pusher motor, accounting for ESC and propeller efficiency, is

Pcruise,req =

Tpusher Vc

ηprop ηESC

=

## ρV³

c S Ccruise
D

## 2 ηprop ηESC

(20)

Hence the measured cruise power P¯ cruise from Eq. (6) fixes the product S Ccruise D

/(ηpropηESC) and, given a nominal S,

allows the aerodynamic and electromechanical loss contributions to be separated.

In hover, the four lift rotors collectively support the weight. The per-rotor ideal hover thrust, the disc loading, and

the ideal induced power per rotor are

## Tper =

W

Nr

, DL =

## Tper

Ad

, P(1)

ideal = Tper√︄

## Tper

## 2ρAd

, | (21)

and the figure-of-merit relating ideal induced power to measured electrical power per rotor is

## FoM =

P

(1)

ideal

P

(1)

measured

=

## Tper√︁ Tper/(2ρAd)

P¯
hover/Nr

(22)

A measured P¯
hover together with a known Ad therefore yields a configuration-level efficiency metric directly comparable

across airframes.

In a coordinated banked turn at bank angle φ, the wing must support the load factor n = 1/cos φ from Eq. (8),

requiring an increased lift coefficient

C

turn
L

(φ) =

2nW

## ρV²S

=

C

cruise
L

cos φ

(23)

The corresponding stall speed in the turn rises as

V

turn

stall (φ) = Vstall,1g√
n = Vstall,1g/

√︁
cos φ, | (24)

which bounds the maximum bank that can be sustained at the cruise airspeed.

For a head-on gust of magnitude Δv that reduces the freestream from V to V − Δv at fixed angle of attack, the lift

drops as the square of velocity,

ΔL

L

=

1 −

Δv

V

2
− 1 ≈ −

2Δv

V

for Δv ≪ V | (25)

The corresponding airspeed margin for stall avoidance at the transition airspeed VT is

Δvmax = Vc − VT, | (26)

so the operational head-wind ceiling satisfies Vwind,max ≲ Δvmax. The CFD case of Sec. VII.D provides the high-α

correction to Eq. (25), where boundary-layer evolution amplifies the linear V

2
scaling.

# D. Computational Aerodynamic Setup

A complementary CFD study is performed in Ansys Fluent (2022 R2 / 2023 R1) under an academic licence.

The computational geometry is an untwisted, extruded S1223 wing panel of 0.292 m (11.5 in) chord and 1.016 m

(40 in) span, matching the as-built airfoil templates released with the dataset; the panel planform area is 0.297 m2

and its aspect ratio is 3.48, so the computed coefficients are finite-wing values rather than two-dimensional section

values. The simulation is steady and incompressible, with a pressure-based solver and the SST k–ω turbulence model

of Menter [35], which is appropriate for attached and mildly separated airfoil flow at moderate Reynolds number.

The freestream condition is V∞ = 15 m/s (the autopilot-held cruise airspeed; see Sec. VI), ρ = 1.225 kg/m3
, and

μ = 1.789 × 10−5 Pa s, with turbulence intensity 1% at the inlet. Eq. (12) gives a chord Reynolds number of ∼3.0 × 10⁵
,

in the low-Reynolds-number range typical of small UAV applications [32, 33]. In the chordwise plane, a symmetric

C-grid mesh extends approximately 10 chord lengths upstream and 20 chord lengths downstream of the airfoil, with

y

+ ≲ 1 on the airfoil surface for boundary-layer resolution. A grid-refinement study comparing coarse, medium, and fine

meshes at the cruise condition confirmed that the integrated lift and drag coefficients change by less than 1% between

the medium and fine meshes; the medium mesh is used for the production angle-of-attack sweep. An angle-of-attack

sweep is performed from α = −5

◦

to +20◦

in 5° increments, and lift and drag are extracted from CFD-Post via the

global-direction force calculator on the wing surface; integrated forces are tabulated for α = −5

◦

to +15◦

## , while the

+20◦
case exhibits the near-stall pressure topology and is used qualitatively. A separate airspeed-deficit case reduces the

freestream from 15 to 13 m/s at α = +15◦
as a quasi-steady estimate of gust-induced lift loss per Eq. (25); unsteady gust

aerodynamics are not modelled, so the case is a conservative screening estimate. Convergence is monitored on the

scaled residuals (each < 10−5
) and on the lift and drag force time histories.

# IV. Hardware and Equipment

The test vehicle is a small quadplane VTOL UAV with a high-mounted, high-aspect-ratio main wing and an H-tail

empennage on twin booms (Fig. 3). Four electrically driven lift rotors are mounted on the boom centrelines, one rotor at

the front and one at the rear of each boom, giving a conventional “+”/“X” quadcopter arrangement when viewed from

above. A separate brushless pusher motor with a folding propeller is mounted at the rear of the central fuselage and

provides all thrust during forward flight. Control surfaces include differential ailerons on the main wing, an elevator on

the horizontal stabilizer, and rudders on the twin vertical fins. The airframe is hand-built in fibreglass/composite skin

over a foam core and is powered by a 6-cell lithium-polymer battery pack. The wing planform and airfoil cross-section

are shown in Fig. 4; the airfoil is a thin, moderately cambered low-Reynolds-number section typical of small UAV

applications [32, 33].

The principal system specifications are summarized in Table 3 and the equipment inventory in Table 4.

# V. Experimental Setup

The flight analyzed in this paper was a ∼24 min session conducted on 4 September 2022 in an open agricultural field

near Dhaka, Bangladesh (23.85° N, 90.51° E, near sea level), of which ∼6.5 min was armed (Fig. 5). Ambient conditions

were tropical with hazy visibility and a moderate steady wind subsequently estimated via Eq. (5). The mission consisted

of: 1) arming and pre-flight hover; 2) vertical climb to ∼45 m AGL; 3) one complete MC→FW front transition; 4) ∼4 min

of fixed-wing cruise in a circular loiter pattern at ∼45 m AGL and ∼15.2 m/s airspeed; 5) one complete FW→MC back

transition; and 6) vertical descent and recovery. A complete time-tagged log (log_5_2022-9-4-18-02-56.px4log)

was recovered from the autopilot SD card; the per-topic CSV bundle is released alongside this paper (see Data

Availability). An overview of the entire armed flight is given in Fig. 6, and the reconstructed three-dimensional flight

path is shown in Fig. 7.

# VI. Flight-Test Results

This section reports the results of the pipeline of Sec. III applied to the recorded flight log: hover (Sec. VI.A),

transition (Sec. VI.B), power and energy (Sec. VI.C), lateral-directional cruise (Sec. VI.D), and longitudinal trim

(Sec. VI.E). The aerodynamic interpretation appears in its own section (Sec. VII).

# A. Hover-Phase Stability

Figure 8 shows p, q, r over a window spanning the last ∼11 s of hover, the 4.5 s MC→FW transition, and the first

∼9 s of cruise. The hover rates are tightly bounded:

p¯hover = +0.51 ± 6.29 deg/s, | q¯hover = −0.18 ± 3.65 deg/s, | r¯hover = −5.91 ± 8.34 deg/s.

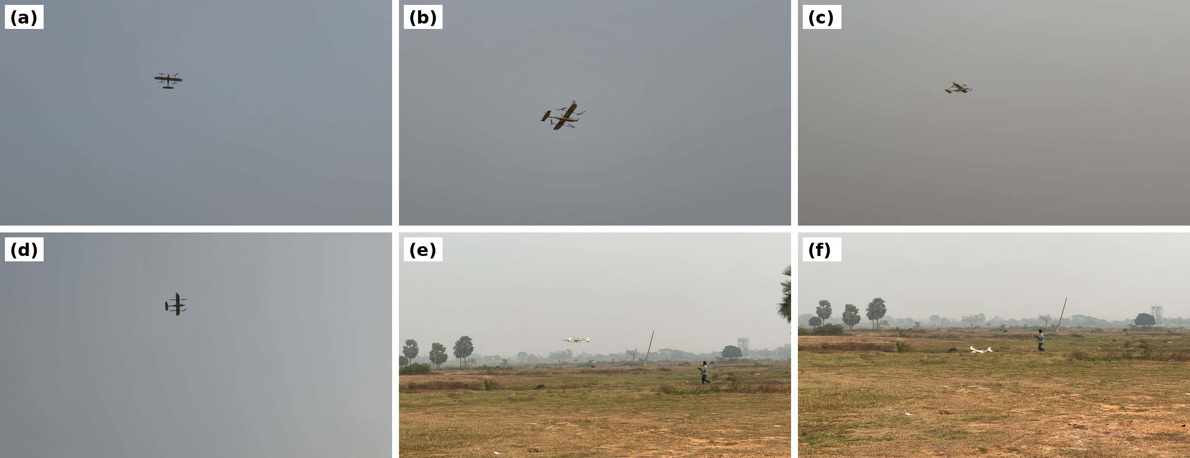
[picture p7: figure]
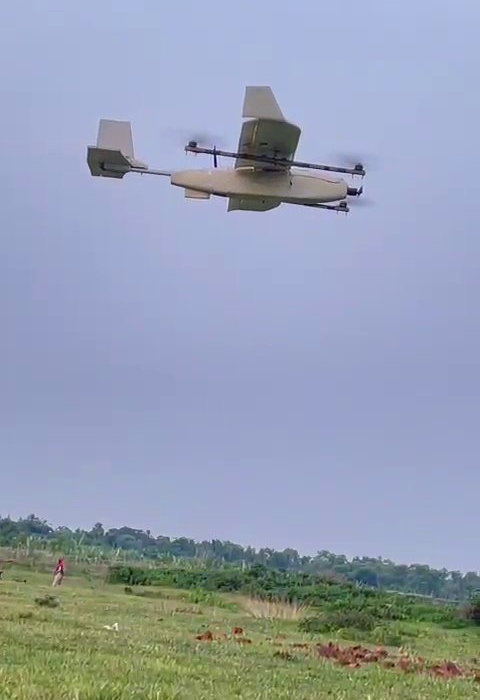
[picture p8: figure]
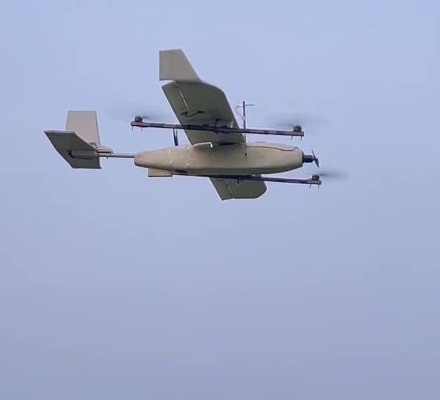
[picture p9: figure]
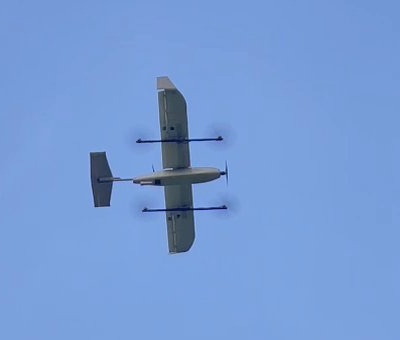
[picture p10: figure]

g) | h) | i)

Fig. 3 Test vehicle in operation: a)–f) ground and in-flight views; g) underside planform in steady cruise; h) side three-quarter view in late transition; i) low-altitude pass over the recovery area.

Mean roll and pitch rates are within sensor noise of zero; the small yaw rate is consistent with deliberate pre-transition

heading alignment. The horizontal ground-speed magnitude Vℎ is essentially zero (0.16 ± 0.07 m/s), while the pitot

reads Vair = 2.93 ± 0.34 m/s (Fig. 9); Eq. (5) gives a wind component along body-x of ∼2.77 m/s.

# B. Hover-to-Forward-Flight Transition

The MC→FW transition begins when the autopilot toggles TransMode from 0 to 1 and ends when the lift rotors are

commanded off. The pitot airspeed at each toggle defines the transition airspeed thresholds (Table 5, Fig. 10).

The front transition starts well below stall (V ≈ 3.83 m/s), with the pusher motor spooling up while the lift rotors

maintain support, and completes at VT = 11.92 m/s (∼28% margin to cruise airspeed). The back-transition trigger

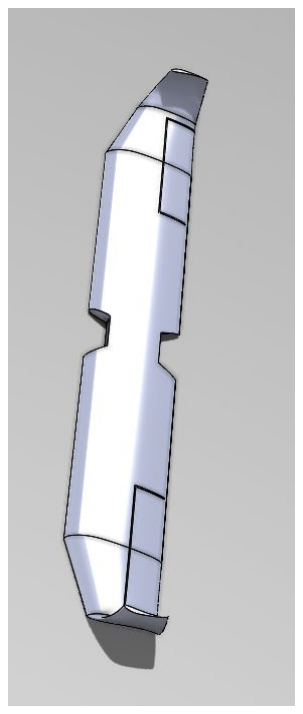
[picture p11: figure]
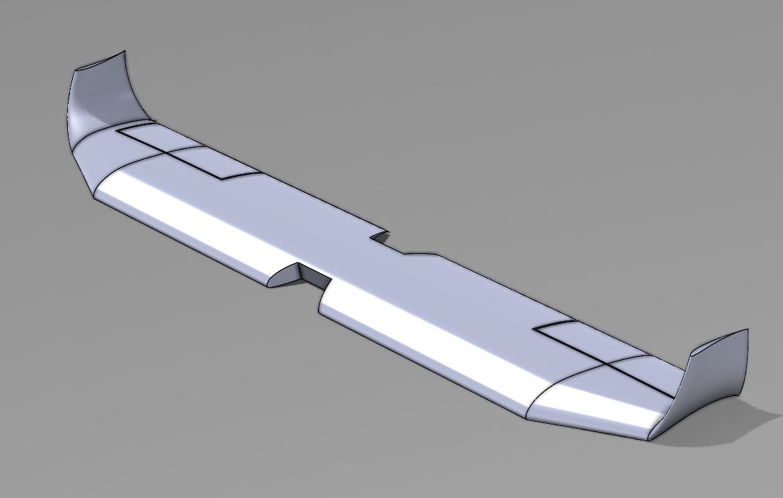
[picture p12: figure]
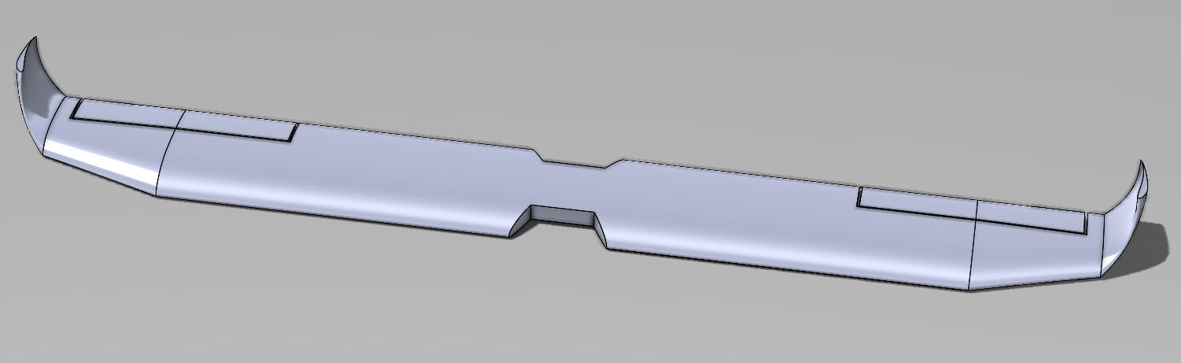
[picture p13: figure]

a) | b) | c)

Fig. 4 Wing geometry: a) isometric CAD view; b) near end-on view showing thickness and tip-cant angle; c) lower perspective showing swept-up tip surfaces and control-surface outlines.

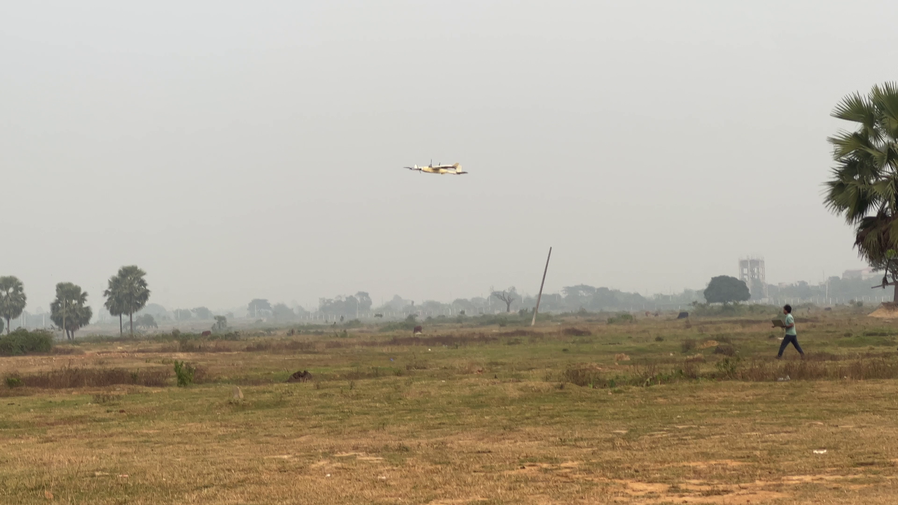
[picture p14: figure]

Fig. 5 Test environment: open field site, operator with ground-control station, and aircraft in low hover during recovery.

(VT,back = 15.62 m/s) is slightly above cruise, so the lift rotors begin spooling up while the wing still has positive lift

authority.

Pitch behaviour during transition (Fig. 11) is a primary indicator of how the airframe converts thrust into airspeed.

From t =1156–1158 s, IAS climbs from 3.8 to ∼6 m/s as the pusher spools up; pitch rises modestly to +2

◦
. Between

1158 and 1159 s the airspeed accelerates through the wing’s low-speed regime and pitch peaks at θmax = +5.40◦
. From

1159 to 1160.75 s the wing develops authority, the elevator actively trims, and pitch settles to the cruise mean of −0.57◦ .

Transition body-rate peaks are |p|max ≈ 55.5

◦

# /s, |q|max ≈ 35.1

◦
/s, |r|max ≈ 35.0

◦
/s (Fig. 8, gold region), well below

the PX4 default saturation limit (∼220 ◦

/s). The back transition completes in 1.86 s with body rates ≤ 20 ◦ /s throughout.

Table 3 System specifications of the test quadplane. Values marked † are estimated from imagery and component sizes; remaining values are derived from the flight log of Sec. V.

Category | Parameter | Value

## Configuration

Aircraft class | Hybrid quadplane VTOL (lift+cruise)
Lift propulsion | 4× brushless DC, boom-mounted
Cruise propulsion | 1× brushless DC pusher (rear fuselage)
Control surfaces | 2 aileron, 1 elevator, 2 rudder

Geometry

Wing configuration | High-mounted, high aspect ratio
Empennage | H-tail on twin booms
Wingspan b | ∼2.0 m†
Wing chord c | ∼0.25 m†
Reference area S | ∼0.5 m2† (estimated from photogrammetry)
Fuselage length | ∼1.7 m†

## Mass / Loading

Gross mass m | ∼4 kg to 6 kg†
Wing loading W/S | ∼80 N/m2 to 120 N/m2†
Hover disc loading W/(Nr Ad) | ∼30 N/m2 to 50 N/m2†

Performance (measured)

Cruise airspeed Vc | 15.19(59) m/s
Front-transition airspeed VT | 11.92 m/s
Back-transition airspeed VT,back | 15.62 m/s
Front-transition duration | 4.53 s
Back-transition duration | 1.86 s
Typical bank in turn | |φ| ≈ 25◦

## Electrical

Battery | 6S LiPo, ∼10 A h, ∼222 W h
Mean hover power | 1269(24) W
Mean cruise power | 378(131) W
Peak transition power | 1597 W (∼4 s duration)

Endurance / Range

Pure-hover endurance (theoretical) | ∼10.5 min
Pure-cruise endurance (theoretical) | ∼35 min
Practical cruise range | ∼20 km

## Autopilot

Flight stack | PX4 v1.7.0 (open-source)
Log format | PX4 legacy sdlog2 (binary)

# C. Power and Energy Budget

Phase-resolved electrical power is summarized in Table 6 and Fig. 12.

The hover-to-cruise power ratio is P¯

hover/P¯
cruise = 1269/378 ≈ 3.36, the front-transition peak is 1597 W sustained

for ∼4 s (sets ESC/battery peak), and the avionics baseline is 97 W (∼25% of cruise). Applying Eq. (6) with

Epack ≈ 223 W h gives a pure-hover endurance ∼10.5 min and a pure-cruise endurance ∼35 min (theoretical range

∼31 km). A practical mission with 30% pack reserve and ∼8 W h hover overhead yields ∼20 km of usable cruise range.

Hover power is remarkably steady (σP/P¯≈1.9%). Applying Eq. (20) with the measured P¯
cruise ≈ 378 W and an assumed

Table 4 Equipment inventory of the test airframe. Items marked ‡ are typical of PX4-compatible builds of this class and reflect the as-built configuration; the published telemetry is independent of the specific manufacturer where not stated otherwise.

Subsystem | Component | Specification / Description

### Avionics

Flight controller | Pixhawk-class, PX4-compatible flight controller
IMU | MEMS 3-axis accelerometer + gyro‡
Magnetometer | 3-axis digital magnetometer‡
Barometer | Digital pressure altimeter‡
GPS receiver | u-blox-class L1 with integrated compass‡
Airspeed sensor | Pitot tube + differential pressure transducer

### Communications

Telemetry | SiK-compatible 433 MHz radio modem‡
RC receiver | SBUS / PPM‡
Ground station | QGroundControl (PX4 ecosystem)

# Lift propulsion (×4)

Motor | Brushless DC outrunner, ∼600 kV to 900 kV‡
Speed controller | BLHeli ESC, ≥ 25 A continuous‡
Propeller | Fixed-pitch, ∼10–12 in diameter‡

### Cruise propulsion (×1)

Motor | Brushless DC, ∼700 kV to 900 kV‡
Speed controller | BLHeli ESC, ≥ 30 A continuous‡
Propeller | Folding, ∼10–13 in diameter‡

### Actuation

Aileron servos (×2) | Standard hobby-grade, ∼0.10 s/60◦‡
Elevator servo (×1) | Standard hobby-grade‡
Rudder servos (×2) | Standard hobby-grade‡

### Power

Battery pack | 6S LiPo, nominal 22.2 V, ∼10 A h
Power module | PX4-compatible V+I sensor, in-line

### Airframe

Wing | Fibreglass/composite skin over foam core
Fuselage | Fibreglass/composite shell
Booms | Twin carbon-fibre booms with 4× lift rotors

Table 5 Transition airspeed thresholds and durations from the TransMode flag toggles.

Event | Time, s | IAS, m/s
Front-transition commit | 1156.22 | 3.83
Front-transition complete | 1160.75 | 11.92 (= VT )
Back-transition commit | 1407.32 | 15.62 (= VT,back)
Back-transition complete | 1409.18 | 12.88
Front-transition duration | — | 4.53 s
Back-transition duration | — | 1.86 s
ηpropηESC ≈ 0.45 gives an aerodynamic Tpusher | ≈ 11.3 N and a lift-to-drag ratio at cruise ≈ W/Tpusher in the range

3.5–5.0 for the 4–6 kg mass band—roughly half the clean-panel maximum of ∼10 from the Fluent polar (Sec. VII.B),

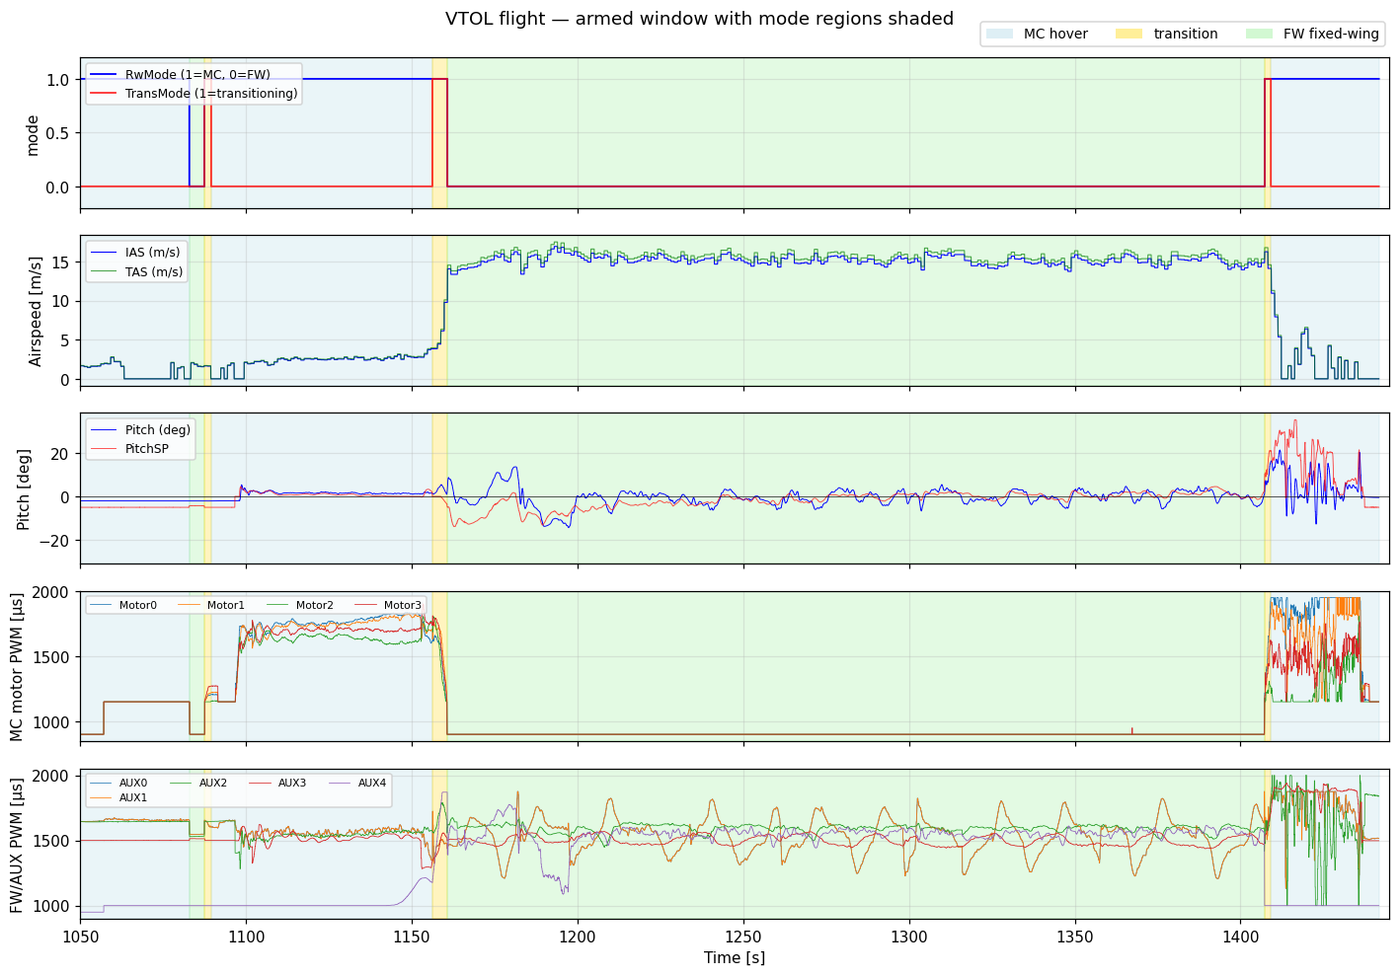
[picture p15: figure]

Fig. 6 Armed-flight overview: mode flags, airspeed, pitch and setpoint, and lift-motor and pusher PWM commands, with flight phases shaded.

Table 6 Phase-resolved electrical power and energy.

Phase | Duration, s | Mean P, W | Peak P, W | Energy, W·h
Pre-takeoff (avionics) | 27 | 97 ± 12 | 130 | 0.73
Climb-out (MC) | 50 | 1010 ± 407 | 1244 | 14.01
Stable hover (MC) | 11 | 1269 ± 24 | 1333 | 3.92
Front transition (MC→FW) | 4.5 | 1368 ± 146 | 1597 | 1.73
Cruise (FW) | 235 | 378 ± 131 | 1010 | 24.81
Back transition (FW→MC) | 1.9 | 380 ± 13 | 393 | 0.20
Landing (MC) | 31 | 890 ± 253 | 1245 | 7.71

the deficit reflecting fuselage, boom, stopped-rotor, and trim drag absent from the panel model. All weight-derived

quantities inherit the 4–6 kg mass-estimate uncertainty and are therefore quoted as ranges. The measured pack-level

power profile sets the requirements on the on-board energy-management layer, for which data-driven state-of-charge

estimation and balancing schemes [36, 37] are an active research direction.

# D. Lateral-Directional Cruise Behaviour

The 235 s cruise window is a continuous circular loiter at ∼45 m AGL. The autopilot holds IAS to 15.19 ± 0.59 m/s

(4% of setpoint) and altitude to ±2 m. Figure 13 shows the bank-angle trace and distribution: the aircraft spends 83.8% of

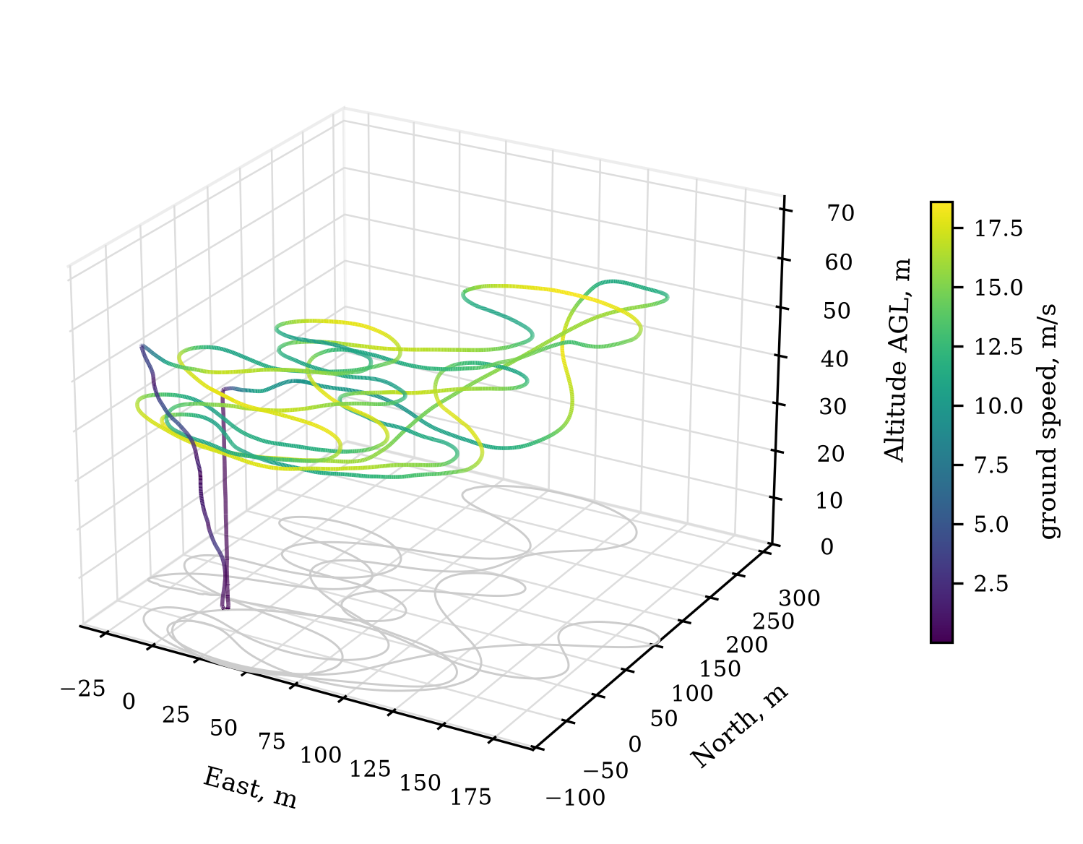
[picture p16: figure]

Fig. 7 Three-dimensional flight path reconstructed from the local-position estimator, coloured by ground speed; the gray curve is the ground-track projection.

cruise turning (|φ| > 10◦
), with mean right-turn bank +27.1

◦
, mean left-turn bank −23.1

◦
, and peaks of +53.8

◦
/−45.6

◦

The mean signed bank +1.03◦
confirms left/right cancellation over the loiter. The turn radius is computed two ways via

Eq. (8): the aerodynamic formula and the kinematic R = Vℎ/|ψ¤|. Median radii of Rformula = 54 m and Rkinematic = 48 m

agree to ∼10%, confirming coordinated turning. Typical operating radius is ∼50 m, with tight ∼20 m turns at maximum

bank. Eq. (23) requires C

turn
L

/C

cruise
L

= 1/cos 25◦ ≈ 1.10 at the typical bank; from Fig. 16, this remains well within the

linear regime.

# E. Longitudinal Trim During Cruise

Figure 14 shows the elevator PWM command during cruise, with red dots marking samples satisfying the level-flight

criterion (|φ| < 5

◦

, |ℎ¤| < 0.5 m/s; n = 65 samples). The level-cruise mean is 1607 µs with σ = 11.9 µs, an offset of

+107 µs from neutral. Applying Eq. (9) with δmax =30◦ yields |δ
trim

e

| ≈ 6.4

- with sub-degree jitter, consistent with a

well-tuned pitch-attitude loop.

# VII. Computational Aerodynamic Analysis

To interpret the empirical VT threshold and quantify the wing’s sensitivity to airspeed disturbance, an angle-of-attack

sweep on the wing airfoil was performed in Ansys Fluent following the setup of Sec. III.D. This section reports the

multi-AoA pressure field (Sec. VII.A), the lift and drag polars (Sec. VII.B), qualitative 3D flow visualization (Sec. VII.C),

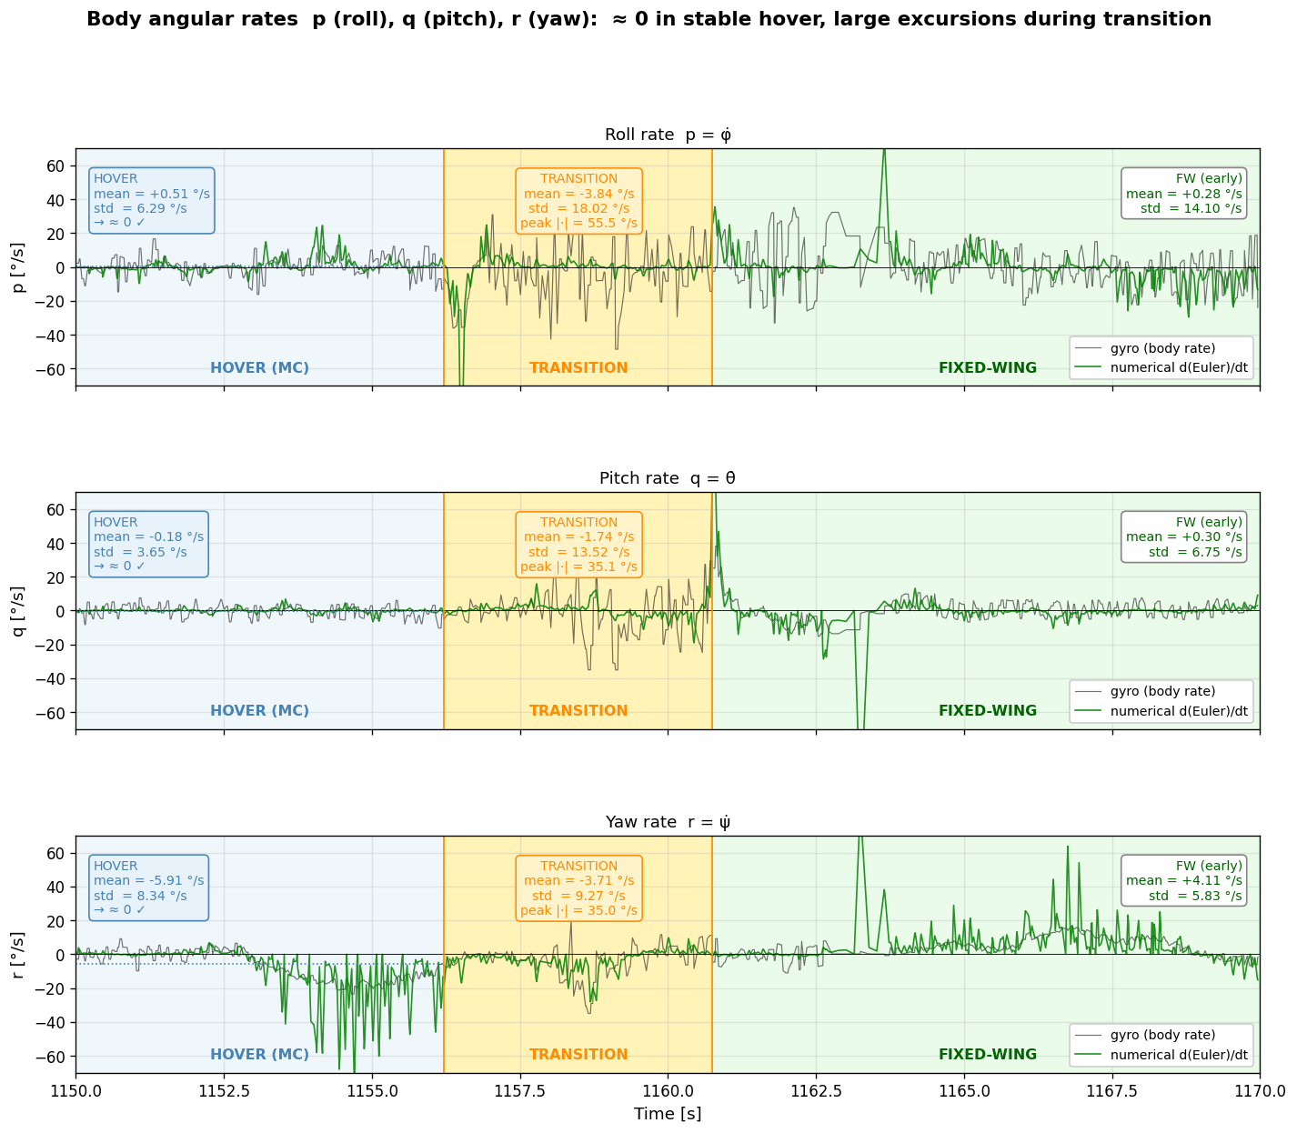
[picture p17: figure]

Fig. 8 Body-axis angular rates across hover, transition, and fixed-wing flight, comparing gyro rates with numerical Euler-angle derivatives.

and the airspeed-deficit case (Sec. VII.D). Implications for VT and the wind ceiling are summarized in Sec. VII.E.

# A. Multi-Angle Pressure Field

Figure 15 shows the mid-span static pressure contour around the wing section at α = −5

◦
, +5

◦

, +15◦

, +20◦
,

V∞ = 15 m/s. At α = −5

◦
the pressure field is nearly fore-aft symmetric with weak upper-surface low pressure, an

essentially zero-lift condition for the cambered section. At α = +5

◦
a clear low-pressure suction peak develops on the

upper surface near the leading edge and a higher-pressure plateau forms on the lower surface, the canonical attached-flow

configuration. At α = +15◦

the suction peak intensifies and migrates toward the leading edge. At α = +20◦ the suction

peak concentrates within a small leading-edge region while the lower-surface pressure plateau is at its strongest; the

topology signals that the upper-surface boundary layer is on the edge of separation.

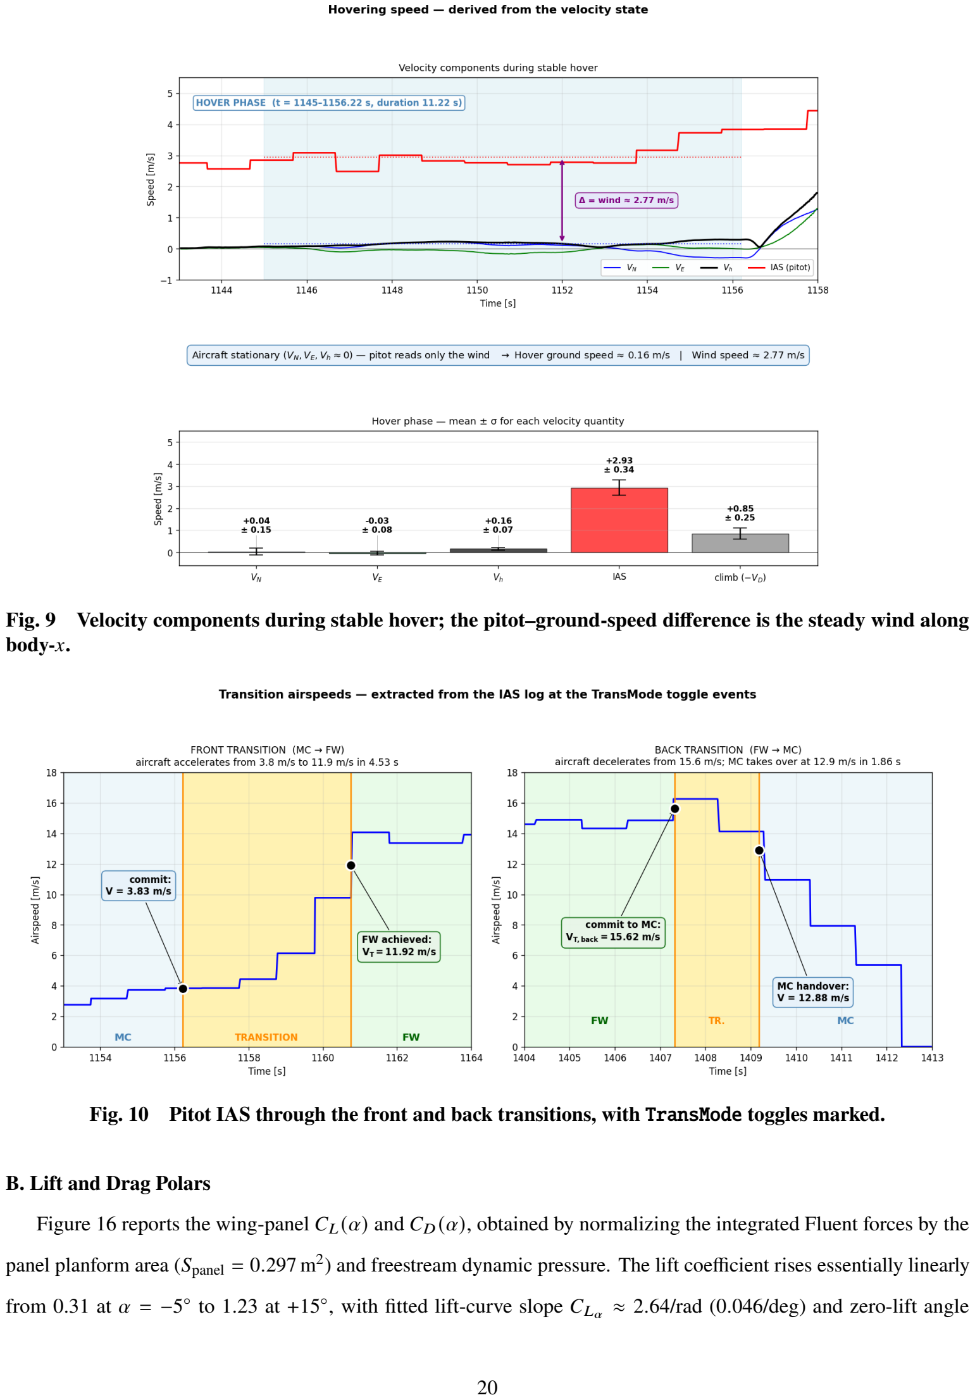
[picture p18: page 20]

Fig. 9 Velocity components during stable hover; the pitot–ground-speed difference is the steady wind along body-x.

Fig. 10 Pitot IAS through the front and back transitions, with TransMode toggles marked.

# B. Lift and Drag Polars

Figure 16 reports the wing-panel CL (α) and CD (α), obtained by normalizing the integrated Fluent forces by the

panel planform area (Spanel = 0.297 m2
) and freestream dynamic pressure. The lift coefficient rises essentially linearly

from 0.31 at α = −5

◦

## to 1.23 at +15◦

, with fitted lift-curve slope CLα ≈ 2.64/rad (0.046/deg) and zero-lift angle

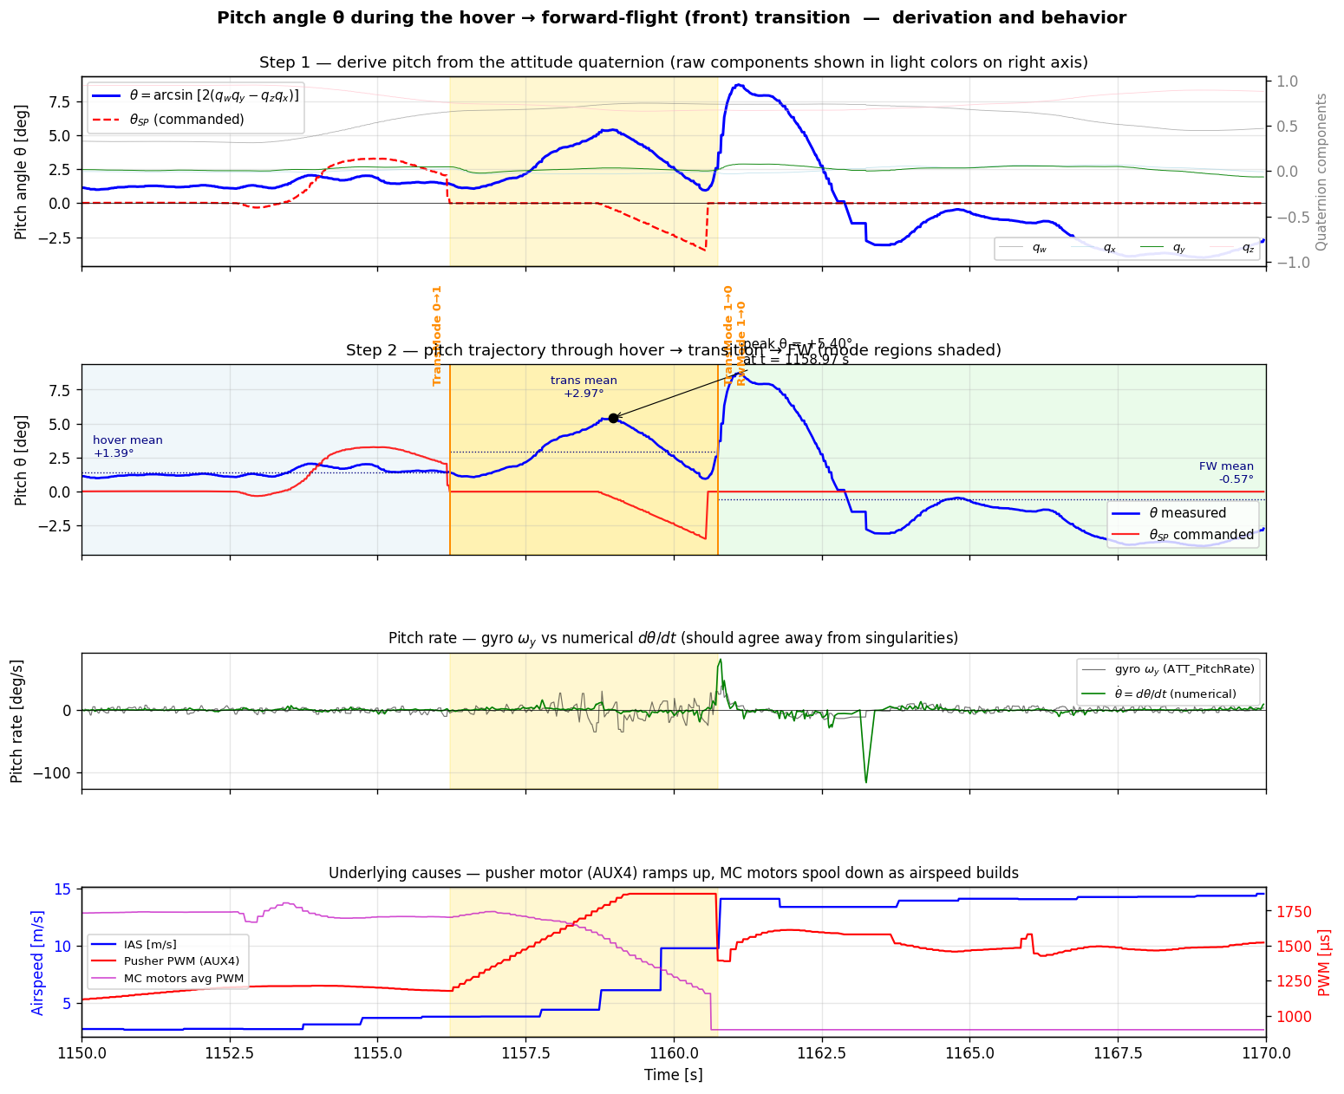
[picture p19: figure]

Fig. 11 Pitch behaviour during front transition: quaternion derivation, pitch trajectory with phase means, pitch rate, and pusher spool-up.

α0L ≈ −12◦
; the strongly negative zero-lift angle reflects the high camber of the S1223 section. The finite aspect ratio

of the panel accounts for most of the reduction from the two-dimensional section slope: lifting-line theory with a

section slope of ∼5.7/rad predicts a wing slope of 3.4–3.7/rad at aspect ratio 3.48, with the residual gap attributable to

low-Reynolds-number viscous decambering [32–34]. The incremental lift per 5° step decreases monotonically toward

+15◦

, and the +20◦ pressure topology of Fig. 15 indicates incipient separation, placing stall onset in the +15◦–+20◦

range. The drag data provide a quantitative validation of the parabolic polar of Eq. (11): a linear fit of CD against C

2
L

[Fig. 16c)] yields CD0 = 0.018 and k = 0.120, corresponding to an Oswald efficiency e = 1/(π AR k) = 0.77—squarely

in the expected range for an untwisted rectangular panel. The panel’s maximum lift-to-drag ratio is ∼10.4, attained near

α = 0

◦

# C. Three-Dimensional Flow Visualization

Qualitative 3D flow visualization (Ansys Discovery, lower-fidelity preview solver) is shown in Fig. 17. Streamlines

and velocity vectors confirm largely attached flow on both surfaces, with mild streamline curvature in the immediate

vicinity of the wing. The 3D views also indicate that spanwise flow is small under symmetric inflow, consistent with the

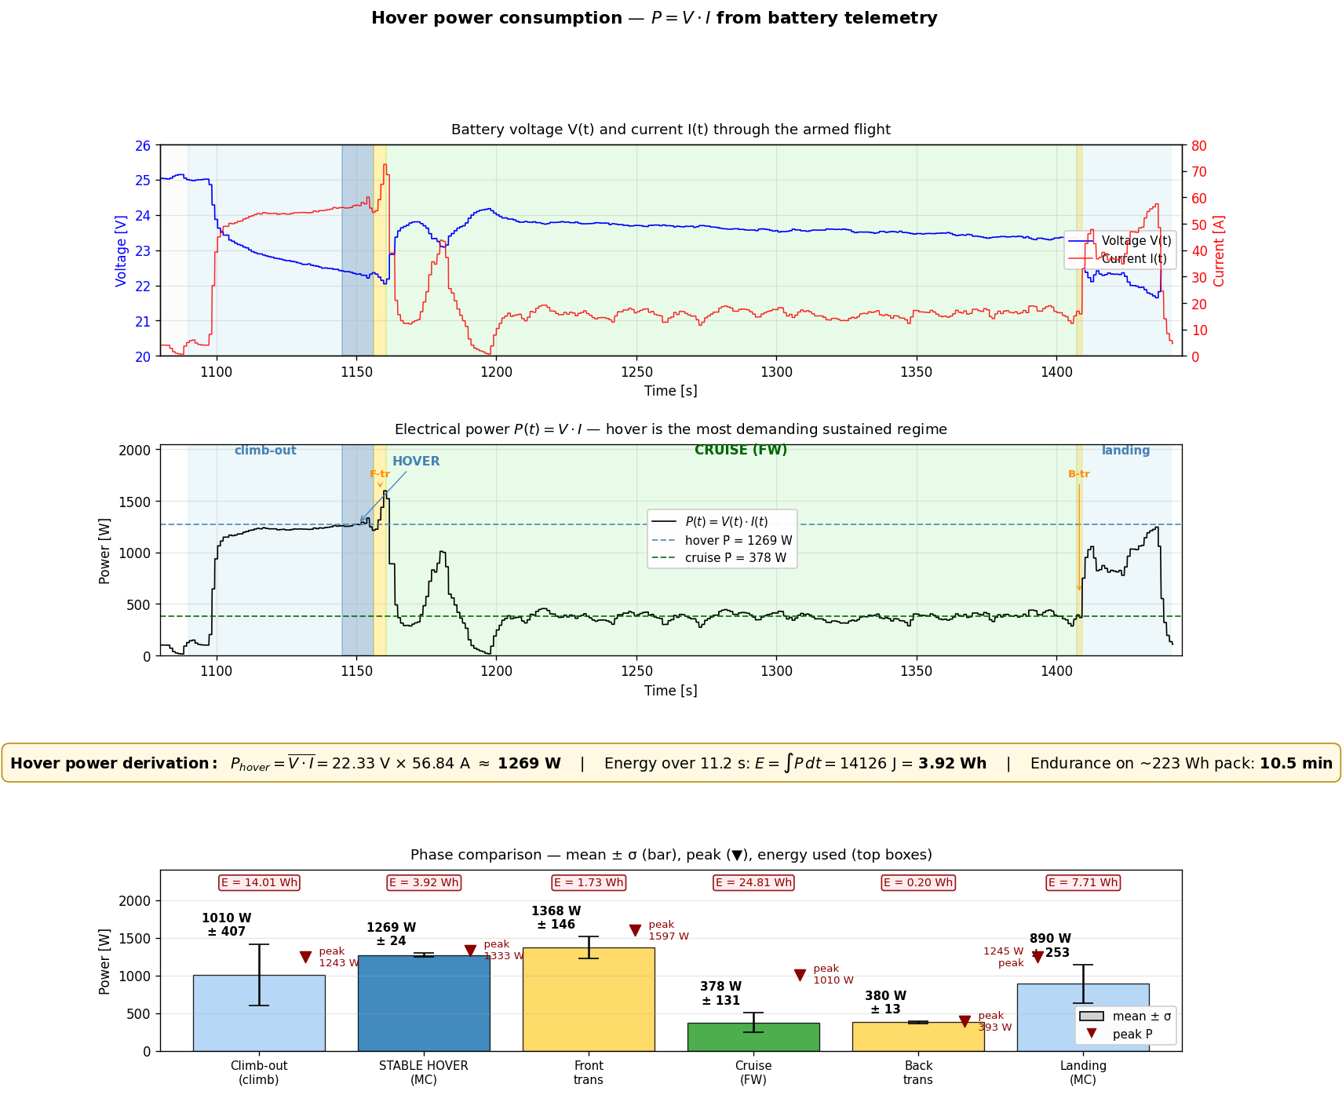
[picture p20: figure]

Fig. 12 Electrical power budget: pack voltage and current, instantaneous power with phase means, and per-phase energy.

near-uniform spanwise loading assumed in interpreting the panel polars. Higher-fidelity 3D simulations are reserved for

future work.

# D. Airspeed-Deficit (Quasi-Steady Gust) Case

A separate Fluent case reduces the freestream from 15 to 13 m/s at α = +15◦
, a quasi-steady representation of a

head-on gust encountered while the wing operates at high-angle-of-attack transition margin; unsteady gust dynamics

are not modelled, so the result is a conservative screening estimate. The integrated lift drops from 50.4 N to 33.8 N,

a ∼33% reduction (Fig. 18). Quadratic dynamic-pressure scaling [Eq. (25)] accounts for 1 − (13/15)

## 2 ≈ 25%; the

remaining ∼8 percentage points correspond to a 10.7% reduction in lift coefficient (from 1.23 to 1.10, the open

marker in Fig. 16a)), reflecting boundary-layer degradation on the suction side near the stall edge, consistent with the

leading-edge-concentrated topology of Fig. 15. This case anchors the operational wind ceiling derived in Sec. VIII.E.

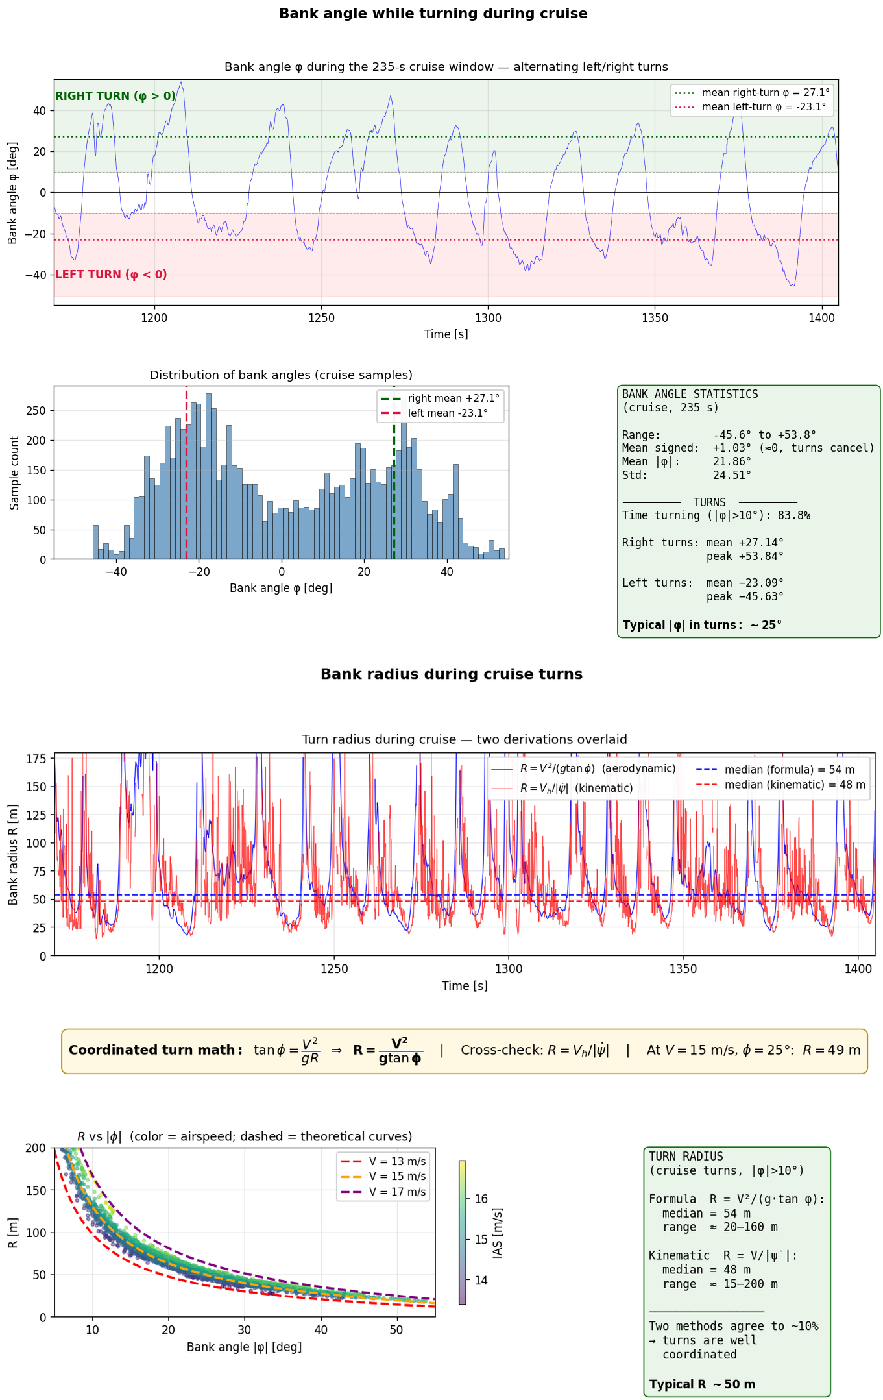
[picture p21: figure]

Fig. 13 Lateral-directional cruise: bank-angle trace and distribution, and turn radius by aerodynamic and kinematic estimates.

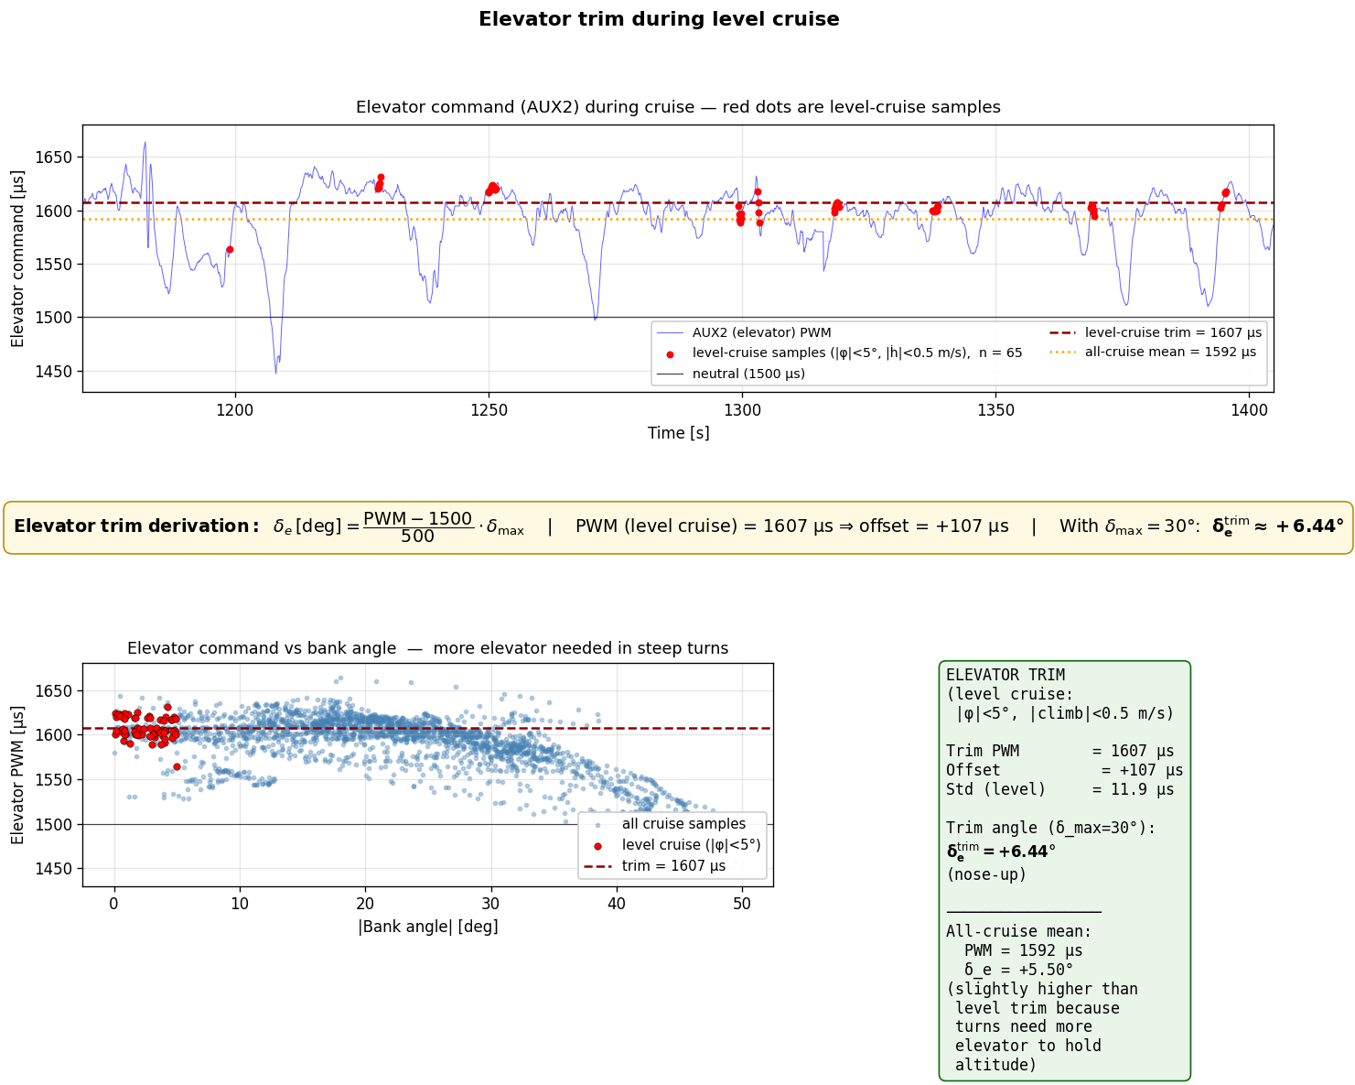
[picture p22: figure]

Fig. 14 Elevator command during cruise with level-cruise samples marked; trim deflection is approximately 6.4°.

# E. Aerodynamic Interpretation of the Transition Airspeed

With the estimated aircraft wing area (S ≈ 0.5 m2
) and the 4–6 kg mass band, the lift balance of Eq. (18) requires

CL = 0.56–0.83 in cruise at 15.2 m/s, rising by the factor (15.19/11.92)

2 ≈ 1.62 to CL = 0.90–1.35 at VT = 11.92 m/s.

The lower half of that requirement sits comfortably in the linear regime of the panel polar [Fig. 16a)]; toward the 6 kg

end it approaches the highest lift coefficient demonstrated by the panel (1.23 at +15◦
). The flight wing, at aspect ratio

∼8, has a steeper lift-curve slope and a higher maximum lift coefficient than the aspect-ratio-3.48 test panel, so the

panel polar is a conservative surrogate; nevertheless, the thinning margin toward the heavy end of the mass estimate

underlines why VT cannot be reduced. An increase in VT, conversely, would waste energy on prolonged transition. The

airspeed-deficit case (Sec. VII.D) shows that a modest 2 m/s disturbance consumes much of this margin at high angle of

attack, providing the quantitative basis for the wind-tolerance rule of Sec. VIII.E.

# VIII. Design Implications

The measured flight characteristics and CFD interpretation of VT motivate several design rules for quadplane-class

VTOL UAVs, stated in inequality form for reusability, with the caveat that the present results derive from a single flight

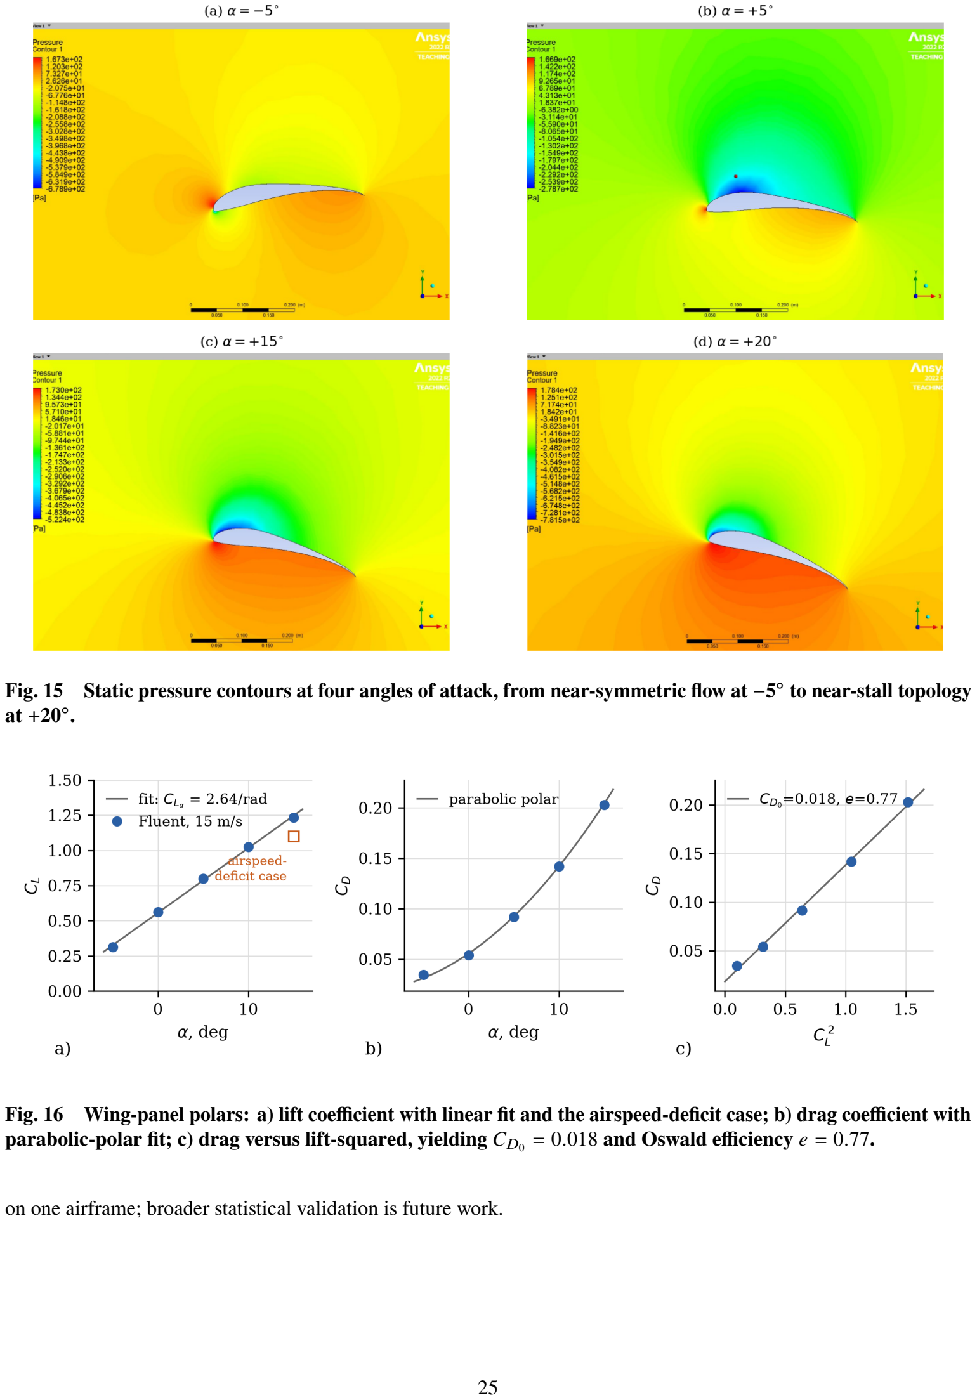
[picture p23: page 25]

# Fig. 15 Static pressure contours at four angles of attack, from near-symmetric flow at −5

◦

# to near-stall topology

at +20◦

Fig. 16 Wing-panel polars: a) lift coefficient with linear fit and the airspeed-deficit case; b) drag coefficient with parabolic-polar fit; c) drag versus lift-squared, yielding CD0 = 0.018 and Oswald efficiency e = 0.77.

on one airframe; broader statistical validation is future work.

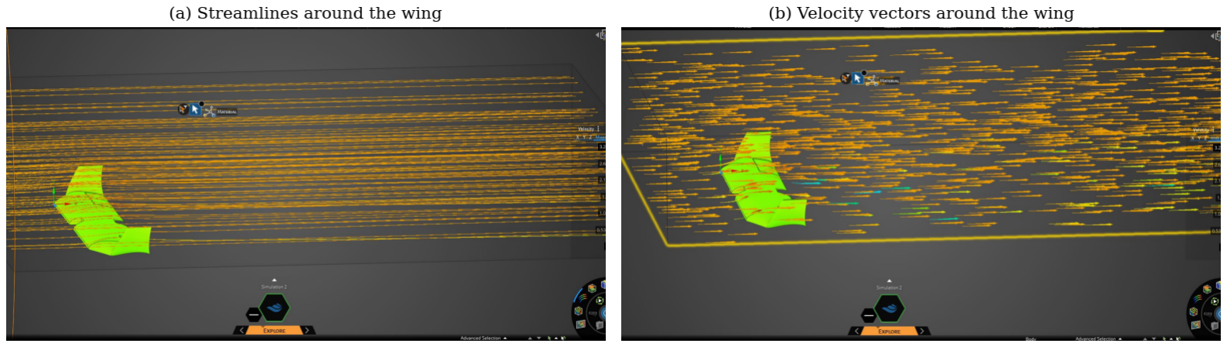
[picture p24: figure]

Fig. 17 Preliminary 3D flow visualization: a) streamlines showing largely attached flow; b) predominantly streamwise velocity vectors.

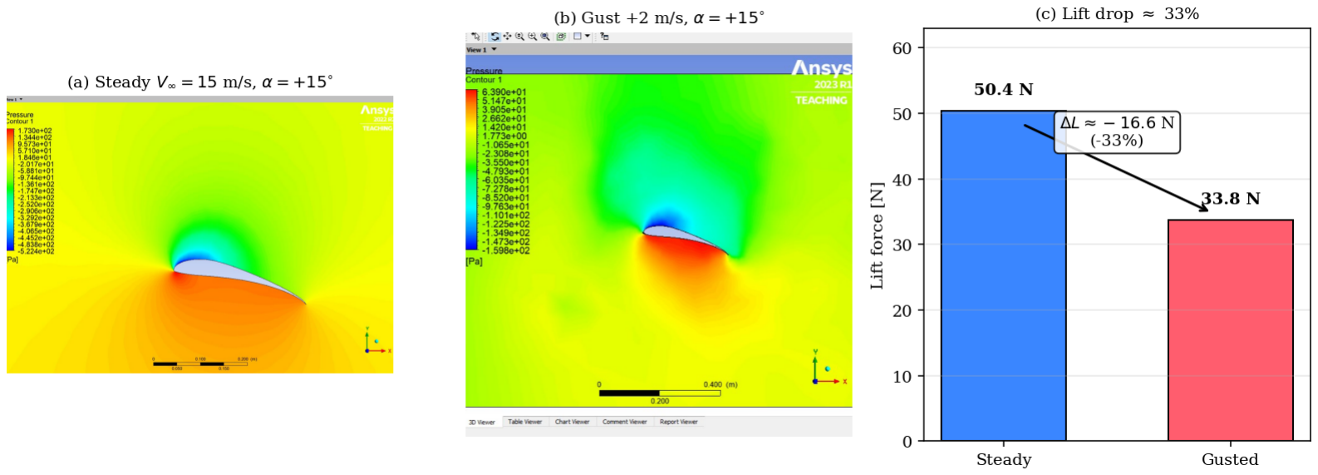
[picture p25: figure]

# Fig. 18 Airspeed-deficit case at α = +15◦ : a) steady and b) reduced-freestream pressure contours; c) integrated

lift drops by approximately 33%, of which 25% is dynamic-pressure scaling and the remainder boundary-layer degradation.

# A. Transition Airspeed Margin

With VT = 11.92 m/s sitting ∼28% below cruise (15.2 m/s), the CFD lift curve places the wing well within the

linear CL (α) regime at VT. The measurement and CFD together support

Vcruise ≥ 1.25VT | and | VT,back ≥ Vcruise | (27)

# B. Control Authority Budget

Peak transition body rates of ∼55 ◦

/s (roll) and ∼35 ◦

/s (pitch/yaw) sit well below the PX4 default 220 ◦ /s limits,

giving more than 4× headroom:

Φ¤

controller,max ≥ 4 Φ¤
trans,peak | (28)

# C. Power-System Sizing

Hover (∼1.3 kW sustained) and front transition (1.6 kW transient) define worst-case discharge. For a 223 W h

6S pack (∼10 Ah at 22 V), continuous 60 A implies 6C and peak 72 A implies 7.2C—within commodity 6S LiPo

specifications. Per-rotor hover current of ∼15 A indicates ≥ 25 A ESCs are adequate.

# D. Energy Budget and Range

With Eq. (7), missions with ηhover ≤ 0.10 are cruise-dominated and approach the ∼35 min pure-cruise endurance.

With 30% pack reserve and ∼8 W h hover overhead, practical cruise range is ∼20 km. The avionics baseline of 97 W

(∼25% of cruise) is itself a candidate for reduction.

# E. Operational Wind Ceiling

The quasi-steady airspeed-deficit case (Sec. VII.D) shows a 2 m/s airspeed disturbance at α = +15◦ removes ∼33%

of the lift. With Eq. (26), a conservative operational ceiling is

Vwind,max ≲ Vcruise − VT ≈ 3.3 m/s, | (29)

or larger only with confirmed gust-rejection authority. Adaptive transition strategies in gust-heavy environments are an

active research direction [21].

# F. Configuration Choice

The lift+cruise layout offers two advantages consistent with comparative analyses [1, 2, 8]: mode independence (lift

rotors decoupled from pusher and wing, eliminating tilt-mechanism complexity [16, 18]) and clean stall margins (all

four lift rotors idle in cruise). The trade-off is that the lift rotors and booms are parasitic in cruise, observable in the

cruise/hover ratio.

# IX. Conclusions

Flight-test telemetry from a small quadplane VTOL UAV, recorded by an open-source PX4 autopilot in the legacy

sdlog2 format, has been combined with an Ansys Fluent angle-of-attack sweep of a finite-span S1223 wing panel

to characterize the hover phase, the MC→FW transition, the FW cruise, and the FW→MC back transition. The

empirical pipeline is reproducible from the binary log; the CFD provides the physical interpretation of the empirical

transition airspeed. A comparison table (Table 2) confirms that no prior study covers the same combination of axes

(configuration, methodology, data source, transition-airspeed reporting, transition-duration reporting, power-budget

reporting, lateral-directional characterization, and CFD aerodynamic interpretation) on a quadplane platform.

In hover, body rates are within sensor noise (|p¯|, |q¯| < 0.5

◦
/s) and pitot recovers the steady wind (2.77 m/s). The

MC→FW transition completes in 4.53 s at VT = 11.92 m/s with pitch bounded at +5.4

◦
and body rates peaking at

∼55 ◦

/s; the back transition completes in 1.86 s. Cruise airspeed is held within 4% of setpoint with ∼25◦ banks in

coordinated turns of ∼50 m radius, two derivations agreeing to 10%. Elevator trim is δ

trim
e | ≈ +6.4

◦
. The hover-to-cruise

power ratio is 3.36×; transition surges to 1.6 kW.

The computational sweep provides finite-panel lift and drag polars (lift-curve slope 2.64/rad, zero-lift angle −12◦
,

zero-lift drag coefficient 0.018, Oswald efficiency 0.77), identifies stall onset above +15◦
, and shows that a 2 m/s

quasi-steady airspeed deficit removes ∼33% of the lift—supplying the quantitative basis for the operational wind ceiling.

Design implications follow directly from the combined evidence.

The results derive from a single flight on one airframe; broader statistical validation through additional flights and

platforms is required and is the central theme of future work. Planned extensions include higher-fidelity 3D CFD with

confirmed reference area and mass, IMU vibration spectra during cruise vs. hover, per-motor current isolation, and

disc-loading/figure-of-merit estimation once rotor geometry is measured directly. Further methodological extensions

include the integration of safe model-free reinforcement-learning controllers with state and control constraints via

control barrier functions and discrete-event safety supervision over the autopilot’s mode logic, building on the methods

reviewed in the introduction.

# Data Availability

The analysis pipeline operates on per-topic CSV exports of the original PX4 sdlog2 binary log (log_5_2022-9-

4-18-02-56.px4log, 4 September 2022). Thirteen CSV topic files (ATT, ATSP, ARSP, AIRS, BATT, GPOS, GPS, LPOS,

LPSP, OUT0, PWR, RC, STAT), together with a column-level data dictionary, the Ansys CFD and structural-FEA project

files, the S1223 airfoil geometry, the CAD models, and the Python analysis code used to generate flight figures, are

released at the public GitHub repository https://github.com/AdamDony/quadplane-px4-flight-data. The

VTOL mode-flag topic (VTOL) and auxiliary PWM bank (OUT1) did not survive log archival and are not part of the

release; the transition events derived from them are reported in Table 5, and the transition window is independently

visible in the released OUT0 lift-motor channels. An archival snapshot will be deposited on Zenodo, and the DOI will be

inserted upon acceptance.

# Funding Sources

This research did not receive any specific grant from funding agencies in the public, commercial, or not-for-profit

sectors.

# Acknowledgments

The authors gratefully acknowledge the PX4 open-source autopilot project and its developer community for the

telemetry framework that made this analysis possible. An AI assistant (Claude, Anthropic) was used to assist with the

organization of the public data repository and the development of the data-analysis and figure-preparation code; all

analyses, results, and text were reviewed and validated by the authors, who take full responsibility for the content of this

article.

# References

[1] Saeed, A. S., Younes, A. B., Cai, C., and Cai, G., “A Survey of Hybrid Unmanned Aerial Vehicles,” Progress in Aerospace

## Sciences, Vol. 98, 2018, pp. 91–105. https://doi.org/10.1016/j.paerosci.2018.03.007

[2] Osman, M., Aboul-Magd, M. M., and Shaheen, A. A., “A Comprehensive Review of Hybrid VTOL UAV Technologies:

Configurations, Propulsion, and Applications,” Alexandria Engineering Journal, 2025.

[3] Rahman, T., and Islam, M. A., “A Complete Design and Implementation of a Low Cost Remote Controlled Flying Machine with

FPGA-Based Control System,” Proceedings of the 2nd International Conference on Computer and Automation Engineering

## (ICCAE), IEEE, Singapore, 2010, pp. 771–775. https://doi.org/10.1109/ICCAE.2010.5451246

[4] Hossain, M. S., Kabir, A. M., Mazumder, P., Aziz, A., Hassan, M., and Islam, M. A., “Design and Development of a Y4 Copter

Control System,” Proceedings of the UKSim 14th International Conference on Computer Modelling and Simulation, IEEE,

2012, pp. 12–17.

[5] Islam, M. A., Rodriguez, J., Saha, A. K., Hwang, Y., and Jo, B. W., “Design and Implementation of a Variable Camber

Mechanism for a Small Fixed-Wing UAV,” Proceedings of the 2024 IEEE International Conference on Robotics and Biomimetics

(ROBIO), IEEE, 2024, pp. 1676–1681.

[6] Islam, M. A., Rahman, A., Saha, A., and Jo, B. W., “Design, Implementation, and Test Flight of a Lightweight Camber

Morphing Wing Aircraft,” AIAA Aviation Forum and Ascend, AIAA Paper 2025-3524, 2025.

[7] Islam, M. A., Rahman, A., Saha, A., and Jo, B. W., “Design of a 3D-Printed and Modular Camber Morphing Wing Mechanism and

Its Performance Analysis in a Wind Tunnel,” Proceedings of the ASME 2025 International Mechanical Engineering Congress and

Exposition (IMECE), Vol. 3, Memphis, TN, 2025, Art. V003T06A023. https://doi.org/10.1115/IMECE2025-166937

[8] Bacchini, A., and Cestino, E., “Electric VTOL Configurations Comparison,” Aerospace, Vol. 6, No. 3, 2019, Paper 26.

## https://doi.org/10.3390/aerospace6030026

[9] Maqsood, A., and Go, T. H., “Optimization of Transition Maneuvers Through Aerodynamic Vectoring,” Aerospace Science and

## Technology, Vol. 23, No. 1, 2012, pp. 363–371. https://doi.org/10.1016/j.ast.2011.09.004

[10] Liu, Z., He, Y., Yang, L., and Han, J., “Control Techniques of Tilt Rotor Unmanned Aerial Vehicle Systems: A Review,”

International Journal of Aerospace Engineering, Vol. 2018, 2018, Paper 6315856. https://doi.org/10.1155/2018/

## 6315856 (https://doi.org/10.1155/2018/6315856)

[11] Beach, J. M., Argyle, M. E., McLain, T. W., Beard, R. W., and Morris, S., “Tailsitter Attitude Control Using Resolved

Tilt-Twist,” Proceedings of the 2014 International Conference on Unmanned Aircraft Systems (ICUAS), IEEE, Orlando, FL,

## 2014, pp. 768–779. https://doi.org/10.1109/ICUAS.2014.6842322

[12] Lyu, X., Gu, H., Zhou, J., Li, Z., Shen, S., and Zhang, F., “A Hierarchical Control Approach for a Quadrotor Tail-Sitter VTOL

UAV and Experimental Verification,” Proceedings of the 2017 IEEE/RSJ International Conference on Intelligent Robots and

Systems (IROS), IEEE, Vancouver, Canada, 2017, pp. 5135–5141. https://doi.org/10.1109/IROS.2017.8206400

[13] Verling, S., Weibel, B., Boosfeld, M., Alexis, K., Burri, M., and Siegwart, R., “Full Attitude Control of a VTOL Tailsitter UAV,”

Proceedings of the 2016 IEEE International Conference on Robotics and Automation (ICRA), IEEE, Stockholm, Sweden, 2016,

## pp. 3006–3012. https://doi.org/10.1109/ICRA.2016.7487466

[14] Kubo, D., and Suzuki, S., “Tail-Sitter Vertical Takeoff and Landing Unmanned Aerial Vehicle: Transitional Flight Analysis,”

## Journal of Aircraft, Vol. 45, No. 1, 2008, pp. 292–297. https://doi.org/10.2514/1.30122

[15] Ritz, R., and D’Andrea, R., “A Global Controller for Flying Wing Tailsitter Vehicles,” Proceedings of the 2017 IEEE

International Conference on Robotics and Automation (ICRA), IEEE, Singapore, 2017, pp. 2731–2738. https://doi.org/

## 10.1109/ICRA.2017.7989318 (https://doi.org/10.1109/ICRA.2017.7989318)

[16] Geuther, S. C., North, D. D., and Busan, R. C., “Investigation of a Tandem Tilt-Wing VTOL Aircraft in a Sub-Scale Free-Flight

Test,” NASA TM-2020-5003178, NASA Langley Research Center, Hampton, VA, 2020.

[17] Yeh, Y. L., Yan, X., and Du, S., “Inverse Machine Learning Framework for Optimizing the Takeoff Performance of a Tilt-Wing

eVTOL Vehicle,” AIAA Aviation 2023 Forum, AIAA Paper 2023-3593, San Diego, CA, 2023. https://doi.org/10.2514/

## 6.2023-3593 (https://doi.org/10.2514/6.2023-3593)

[18] May, M. S., Milz, D., and Looye, G., “Transition Strategies for Tilt-Wing Aircraft,” AIAA SciTech 2024 Forum, AIAA Paper

## 2024-1289, Orlando, FL, 2024. https://doi.org/10.2514/6.2024-1289

[19] Mathur, A., and Atkins, E. M., “Experimental Aerodynamic Analysis of a QuadPlane Unmanned Aircraft System,” Journal of

## Aircraft, Vol. 60, No. 4, 2023, pp. 1323–1328. https://doi.org/10.2514/1.C036797

[20] Lee, S., and Kim, S., “Model Predictive Control-Based Longitudinal Control Design for a Fixed-Wing VTOL UAV,” AIAA

SciTech 2024 Forum, AIAA Paper 2024-0141, Orlando, FL, 2024. https://doi.org/10.2514/6.2024-0141

[21] Chiwande, S., “INAV-Based Adaptive Transition Control for QuadPlane VTOL UAVs in Urban Wind Gust Environments,”

SSRG International Journal of Electrical and Electronics Engineering, Vol. 12, No. 8, 2025, pp. 186–195.

[22] Dong, W., Dony, M. N.-A., and Rafat, M., “Tracking Control of Vertical Take-Off and Landing Vehicles with Parametric

Uncertainty,” International Journal of Adaptive Control and Signal Processing, Vol. 34, 2020. https://doi.org/10.1002/

## acs.3143 (https://doi.org/10.1002/acs.3143)

[23] Dony, M. N.-A.-A., and Dong, W., “Distributed Robust Formation Flying and Attitude Synchronization of Spacecraft,” Journal

of Aerospace Engineering, Vol. 34, No. 3, 2021. https://doi.org/10.1061/(ASCE)AS.1943-5525.0001262

[24] Dony, M. N.-A.-A., “Robust Distributed Formation Control of UAVs with Higher-Order Dynamics,” Ph.D. Dissertation, The

University of Texas Rio Grande Valley, Edinburg, TX, 2021.

[25] Dony, M. N.-A.-A., Rafat, M., and Dong, W., “Distributed Command Filtered Robust Tracking Control of Wave-Adaptive

Modular Vessel with Uncertainty,” Proceedings of the 2020 American Control Conference (ACC), IEEE, Denver, CO, 2020,

## pp. 2118–2123. https://doi.org/10.23919/ACC45564.2020.9147520

[26] Dony, M. N.-A.-A., and Arhin, B., “Safe Model-Free Q-Learning for Discrete-Time Fully Cooperative Multi-Input Systems

with State and Control Constraints via Control Barrier Functions,” Research Square preprint, 2025, submitted for publication.

## https://doi.org/10.21203/rs.3.rs-9108014/v1

[27] Dony, M. N.-A.-A., Khallil, M. E., and Ali, M. S., “Adaptive Reinforcement Learning with Control Barrier Functions for Safe

State Avoidance in Discrete Event Systems,” Proceedings of the 8th IEOM Bangladesh International Conference on Industrial

Engineering and Operations Management, Dhaka, Bangladesh, 2025. https://doi.org/10.46254/BA08.20250300

[28] Stevens, B. L., Lewis, F. L., and Johnson, E. N., Aircraft Control and Simulation: Dynamics, Controls Design, and Autonomous

Systems, 3rd ed., Wiley, Hoboken, NJ, 2016.

[29] Etkin, B., and Reid, L. D., Dynamics of Flight: Stability and Control, 3rd ed., Wiley, New York, 1995.
[30] Beard, R. W., and McLain, T. W., Small Unmanned Aircraft: Theory and Practice, Princeton University Press, Princeton, NJ,

2012.

[31] Anderson, J. D., Aircraft Performance and Design, McGraw-Hill, New York, 1999.
[32] Selig, M. S., Guglielmo, J. J., Broeren, A. P., and Giguère, P., Summary of Low-Speed Airfoil Data, Volume 1, SoarTech

Publications, Virginia Beach, VA, 1995.

[33] Maughmer, M. D., Axten, R. M., and Metkowski, L. P., “A Wind Tunnel for the Study of Low-Reynolds-Number Airfoils,”

Journal of Aircraft, Vol. 60, No. 6, 2023, pp. 1739–1745.

[34] Hann, R., Hearst, R. J., Sætran, L. R., and Bracchi, T., “Experimental and Numerical Icing Penalties of an S826 Airfoil at Low

Reynolds Numbers,” Aerospace, Vol. 7, No. 4, 2020, Paper 46. https://doi.org/10.3390/aerospace7040046

[35] Menter, F. R., “Two-Equation Eddy-Viscosity Turbulence Models for Engineering Applications,” AIAA Journal, Vol. 32, No. 8,

## 1994, pp. 1598–1605. https://doi.org/10.2514/3.12149

[36] Dony, M. N.-A.-A., and Arhin, B., “Data-Driven Distributed Battery State-of-Charge Balancing Using Neural Network-Based

Open Circuit Voltage Learning,” IFAC Journal of Systems and Control, 2026. https://doi.org/10.1016/j.ifacsc.2026.

## 100415 (https://doi.org/10.1016/j.ifacsc.2026.100415)

[37] Khallil, M. E., Islam, M. A., Dony, M. N.-A.-A., and Ali, M. S., “Comparative Analysis of LSTM and PINN for Internal

Resistance Estimation in Lithium-Ion Batteries,” Proceedings of the 8th IEOM Bangladesh International Conference on Industrial

Engineering and Operations Management, Dhaka, Bangladesh, 2025. https://doi.org/10.46254/BA08.20250259

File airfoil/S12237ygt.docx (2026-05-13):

1in 0in 0inji

0.998in 0.001in 0in ~a

0.994in 0.005in 0in

0.988in 0.01in 0in

0.981in 0.016in 0in

0.971in 0.023in 0in

0.959in 0.029in 0in

0.944in 0.035in 0intgd, ,

o

0.926in 0.041in 0in

0.906in 0.048in 0in n

0.884in 0.054in 0in

0.859in 0.061in 0innubt4

,o.

0.833in 0.067in 0in

0.804in 0.074in 0inuvq6w

0.774in 0.08in 0in

0.742in 0.087in 0in

0.708in 0.093in 0in

0.674in 0.099in 0in

0.638in 0.104in 0in

0.602in 0.109in 0in

0.565in 0.114in 0in

0.527in 0.119in 0inw

0.49in 0.123in 0in

0.453in 0.12dxdxdzexd4z7in 0in

0.417in 0.13in 0in

0.382in 0.133in 0in

0.348in 0.134in 0in

0.315in 0.135in 0inzz

0.283in 0.135in 0in

0.254in 0.133in 0in

0.225in 0.13in 0inxzxdszx,,,excedrin X r4

0.198in 0.126in xdeczrn 0.079in 0in🥓যেকোন লেখা বা ছবি কপি করলে "Recent" এ আসবে। তবে পিন না করলে ১ ঘন্টা পর মুছে যাবেযেকোন লেখা বা ছবি কপি করলে "Recent"4ecz এ আসবে। তবে পিন না করলে ১ ঘন্টা পর মুছে যাবেএখানে একবার প্রেস করলে সেটি ইনপুট বক্সে পেস্ট হবেeexxrxrsxcz

0.052in 0.07in 0izew zzxen

0.039in 0.06in 0idn

0.027in 0.05in 0in

0.018in 0.04in 0in

0.01in 0.03in 0in

0.005in 0.02in 0in

0.00d2s2in 0.01in 0in

0in 0.002ind 0in🥎🎎🎫

0in -0.006in 0in

0.003in -r 0in,,x

0.008in -0.014in 0in

X -0.🎎🎍 0in

0.046in -🥎 0in

0.066in -0.014in 0in

0.088in -0.0 w12in 0in

0.113in -0.009in 0in

0.14in -0.006in 0in

0.17in -0.001in 0in

0.203in 0.005in 0in

0.238in 0.012in 0in

0.277in 0.019in 0in

0.318in 0.027in 0in

0.36in 0.034in 0in

0.405in 0.04in 0in

0.451in 0.046in 0in

0.499in 0.051in 0in

0.546in 0.055in 0in

0.594in 0.058in 0in

0.642in 0.06in 0in

0.688in 0.06in 0in

0.733in 0.059in 0in

0.777in 0.056in 0in

0.817in 0.052in 0in

0.855in 0.047in 0in

0.889in 0.041in 0in

0.92in 0.034in 0in

0.946in 0.026in 0in

0.967in 0.018in 0in

0.983in 0.011in 0in

0.993in 0.005in 0in

0.998in 0.001in 0in

1in 0in 0in

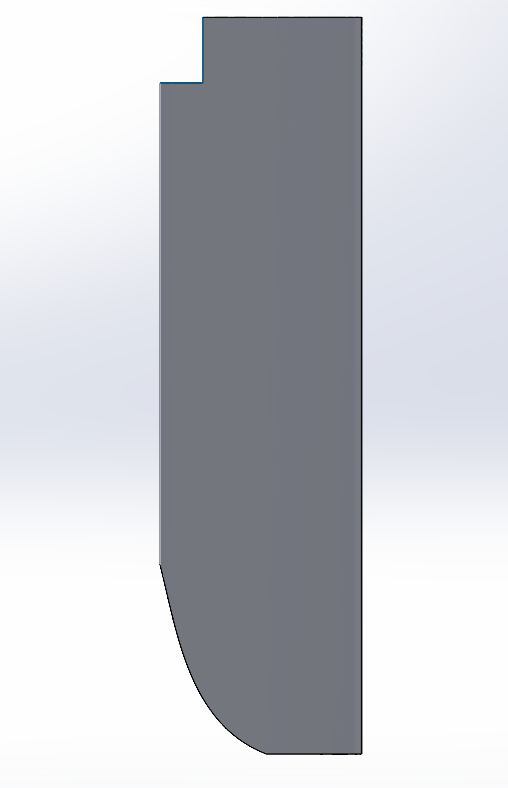
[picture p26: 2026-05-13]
cad/renders/Capture3.PNG

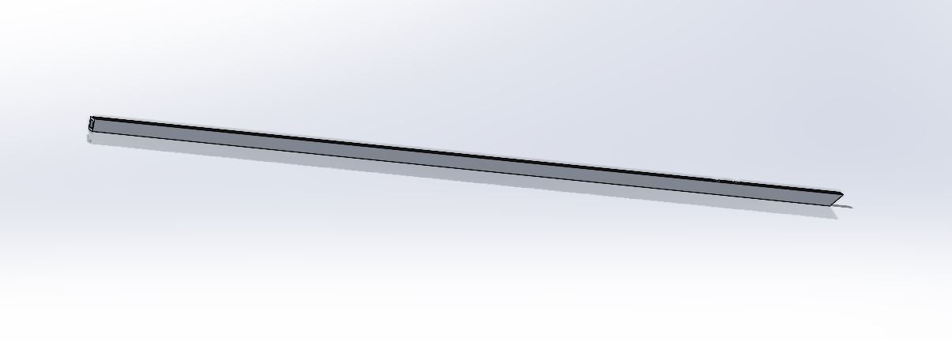
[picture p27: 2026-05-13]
cad/renders/Captur1.JPG

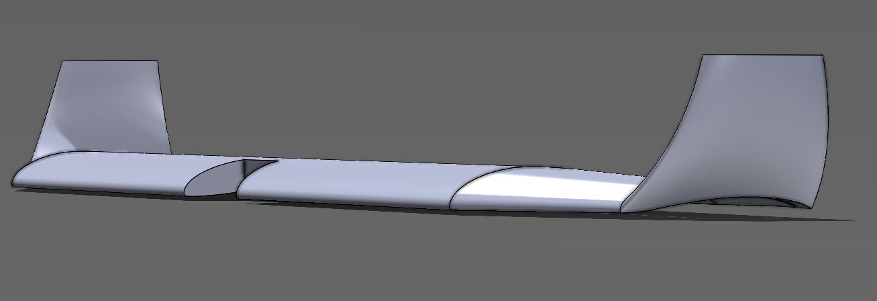
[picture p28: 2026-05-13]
cad/renders/Capture1.JPG

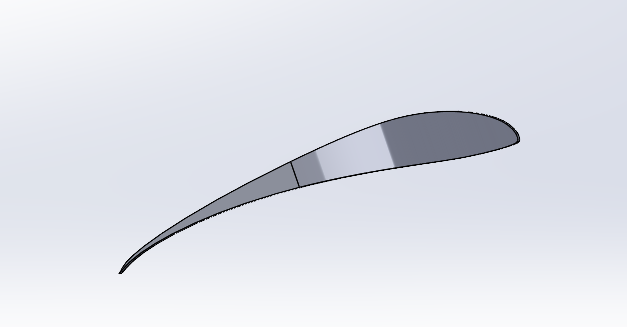
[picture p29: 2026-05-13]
cad/renders/Capture4.PNG

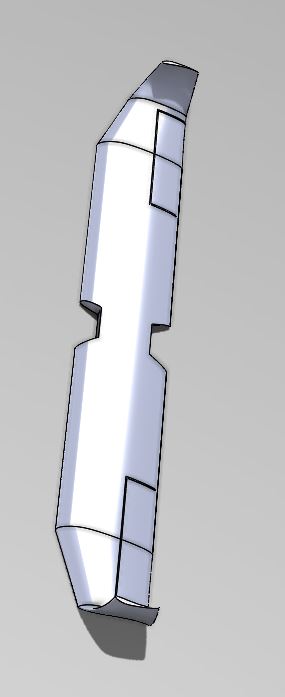
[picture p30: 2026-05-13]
cad/renders/Capture.JPG

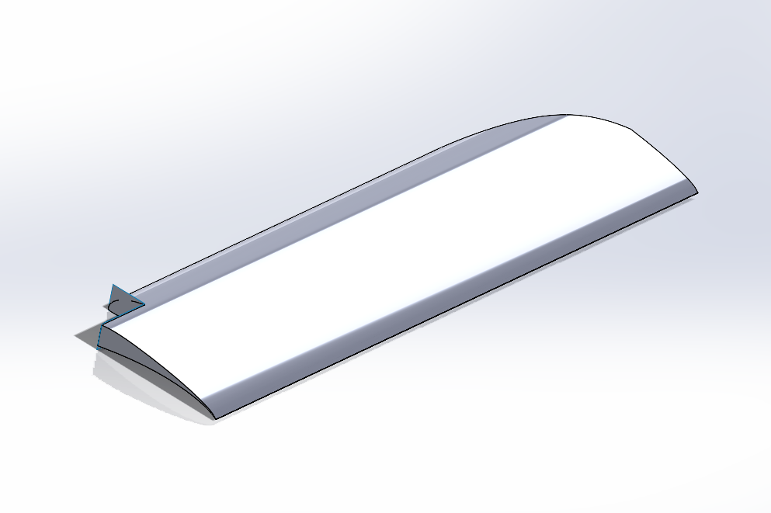
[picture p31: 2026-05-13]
cad/renders/Capture1.PNG

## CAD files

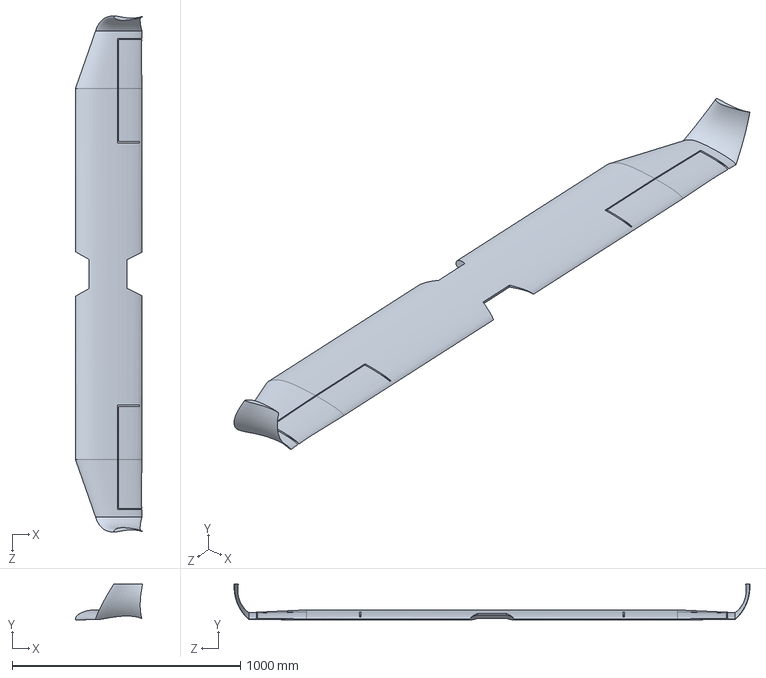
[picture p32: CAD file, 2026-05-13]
cad/WingDraft2.SLDPRT
295.5 x 157.0 x 2263.1 mm

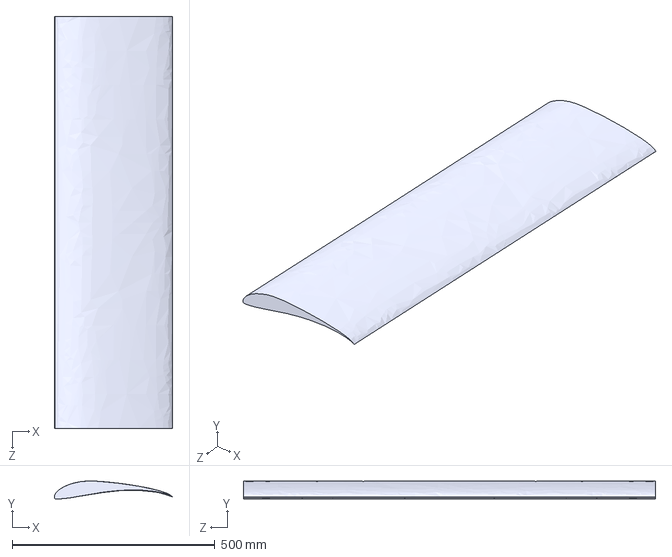
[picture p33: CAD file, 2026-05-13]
cad/WingForSimu.STEP
292.1 x 44.2 x 1016.0 mm

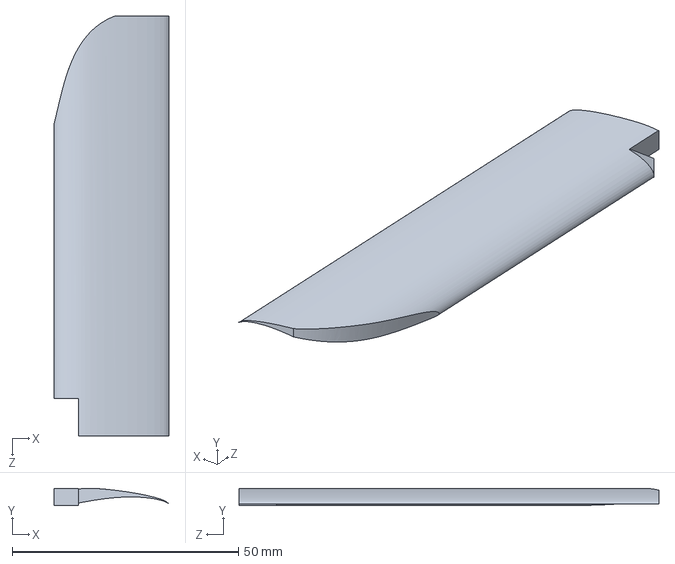
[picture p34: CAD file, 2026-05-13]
cad/WingDraft1.SLDPRT
25.4 x 3.84 x 92.7 mm

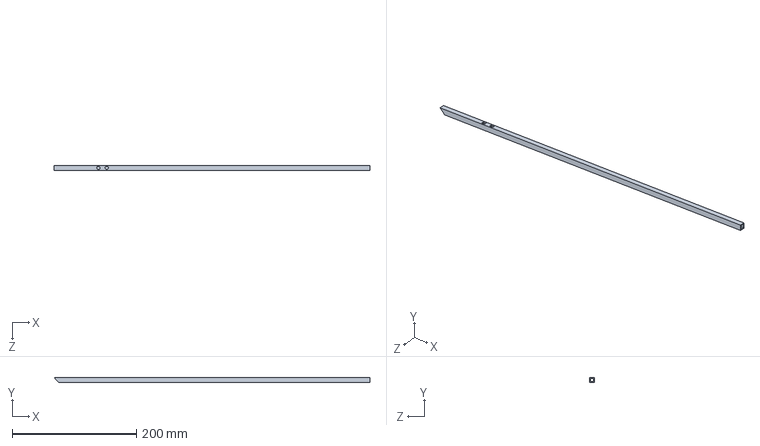
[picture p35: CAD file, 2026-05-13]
cad/Arm.SLDPRT
508.0 x 8.15 x 7.62 mm

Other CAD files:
cad/Drawing1.dwg
cad/WingForSimu.SLDPRT

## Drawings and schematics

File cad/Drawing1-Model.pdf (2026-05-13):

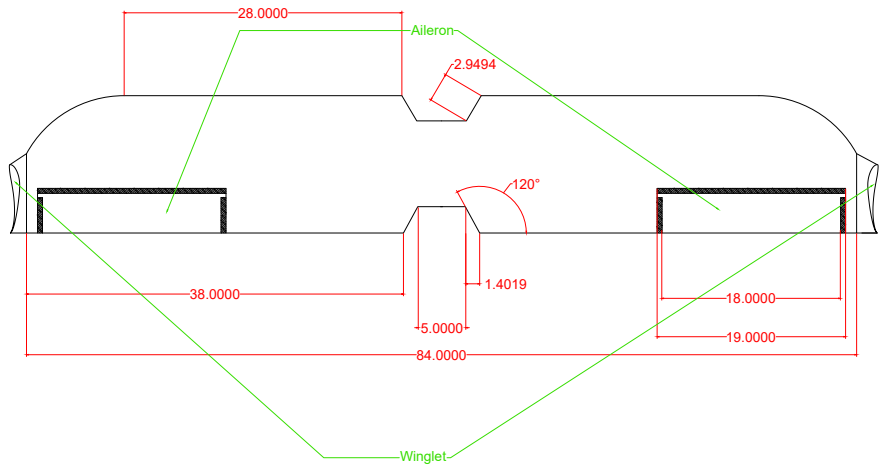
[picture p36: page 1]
18.0000 19.0000 84.0000 Aileron Winglet

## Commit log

2026-07-28 Restructure repository and add flight-analysis toolkit
    - Reorganize ~110 root-level files into data/, cfd/, fea/, airfoil/,
    cad/, media/, docs/ (history preserved via renames)
    - Add analysis/plot_flight.py: regenerates four flight-report figures
    (3-D trajectory, flight overview, ground track, transition dynamics)
    directly from the PX4 telemetry CSVs
    - Add generated figures/ and embed them in a rewritten README with
    headline flight statistics (3.6 km flown, 69 m AGL, 3.2x hover-to-
    cruise power ratio)
    - Add docs/DATA_DICTIONARY.md with column-level semantics for all 13
    telemetry topics; correct the ARSP topic description (attitude-rate
    setpoint, not airspeed) and drop references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
    [AIRS.csv, ARSP.csv, ATSP.csv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]
2026-07-28 Sync author list and hover-power figures with manuscript
2026-07-28 Add CFD polar reduction with finite-panel normalization
    Reduce cfd/polars/LiftDrag.xlsx to finite-wing coefficients using the
    panel geometry measured from cad/WingForSimu.STEP (0.292 m x 1.016 m,
    AR 3.48): C_La 2.64/rad, alpha_0L -12 deg, CD0 0.018, Oswald e 0.77.

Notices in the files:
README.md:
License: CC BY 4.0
